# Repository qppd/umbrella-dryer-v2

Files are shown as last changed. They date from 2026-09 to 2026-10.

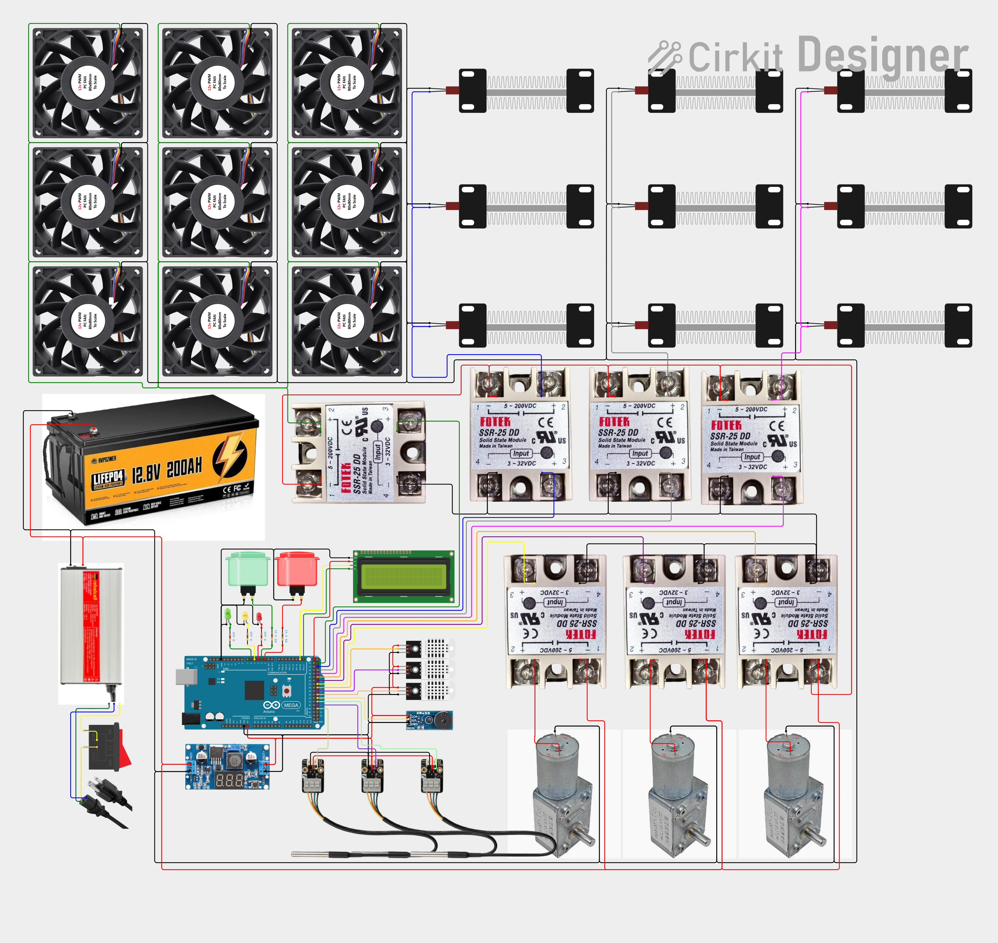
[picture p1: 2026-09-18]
wiring/circuit_image.png

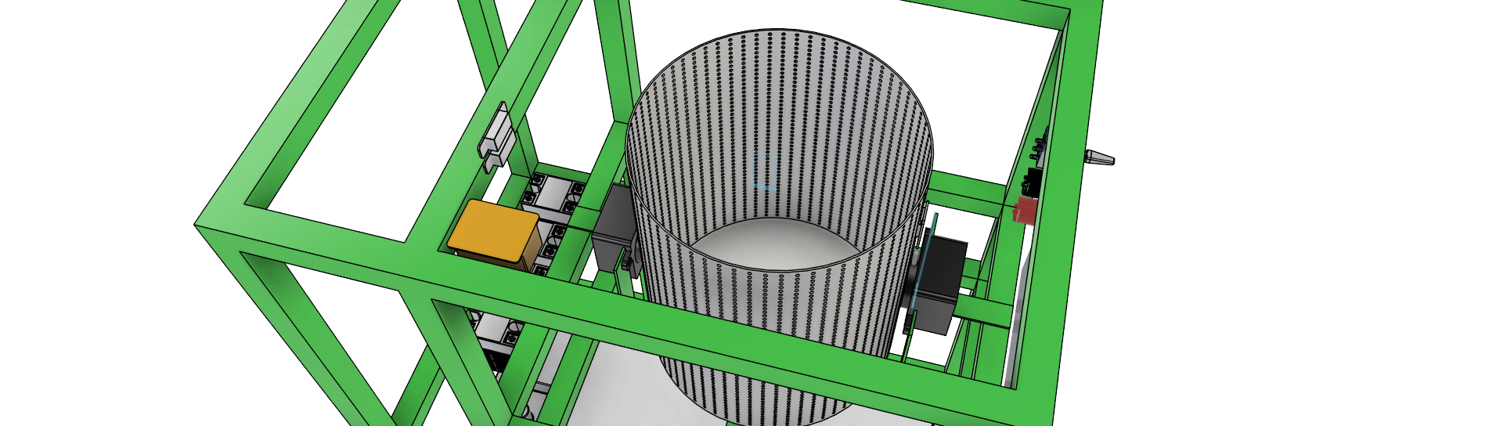
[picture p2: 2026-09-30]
model/UmbrellaDryerV2_8.png

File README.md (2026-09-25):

# Smart Umbrella Dryer

**Design and Development of a Multi-Umbrella Drying System with Energy Efficient Control**
Capstone project (BS Computer Engineering).

Dries **3 umbrellas simultaneously** (or any 1–3 mix) using heated forced air and sensor-based (humidity + temperature) feedback control — powered entirely by a **12V LiFePO4 battery** with energy-efficient staged duty cycling.

## How it works

1. Each umbrella mounts on its **own motorized station** — a SGM-370 worm gear motor (14 kg·cm) driving through a rigid coupling into a 6mm SS shaft (supported mid-span by a UCP06 pillow block), then a 6mm flange coupling to the umbrella hub — inside the drying chamber. Stations run independently; firmware stages one station at a time to stay within the BMS current budget.
2. **9× PTC ceramic heaters (12V 100W)** provide heating (3 per station), switched by **DC-output SSRs (SSR-40DD class)** driven directly from the Mega. **9× AVC 12V 4.5A blowers** circulate warm air (40–60°C) via direct PWM from the Mega.
3. **DHT22** (humidity) + **DS18B20** (heater-zone temp) drive the cycle on the **Arduino Mega 2560** — PREHEAT gates on temperature (45°C), and DRY auto-stops early once chamber humidity bottoms out at ≤ 60% RH (the "energy efficient control" of the study).
4. When chamber humidity drops below threshold → auto-shutoff + buzzer + green LED. Condensate drains passively (sloped floor → drain tube → drip tray).

## Core components

| Subsystem | Component |
|---|---|
| Controller | Arduino Mega 2560 |
| Heat | **9× PTC ceramic heaters 12V 100W** (3 per station), **LCTC DC-DC SSR 40A switched** |
| Rotation | **3× SGM-370 worm gear motors** 12V (14 kg·cm each), LCTC DC-DC SSR 10A switched |
| Fans | **9× AVC 12V 4.5A blowers** (3 per station), PWM via Mega D10/D11/D12 |
| Sensors | DHT22 (humidity) · DS18B20 (heater-zone temp) |
| Lid safety | **Magnetic Door Reed Switch Set NO/NC** (D22 — lid-closed sensor) · **Solenoid Lock 12VDC** (D23 via SSR-10A, fail-secure bolt lock) |
| Thermal safety | PTC self-regulation · firmware 65°C cutoff · BMS |
| UI | 16×2 LCD (I2C, pins 20/21), 3 status LEDs, buzzer, illuminated arcade start button |
| Mechanical | 3× drivetrains (rigid coupling 6×8mm → 6mm SS shaft on UCP06 pillow block → PETIYOUZA 6mm flange coupling), aluminum chassis |

## Where to start (read in this order)

| Order | Doc | Why |
|---|---|---|
| 1 | [docs/BOM.md](docs/BOM.md) | What to buy — printable shopping checklist |
| 2 | [docs/HARDWARE.md](docs/HARDWARE.md) | What each part is and its ratings |
| 3 | [model/README.md](model/README.md) | What you are building — dimensioned views |
| 4 | [docs/BLOCK-DIAGRAM.md](docs/BLOCK-DIAGRAM.md) | How everything wires together |
| 5 | [wiring/README.md](wiring/README.md) | Pin map and all connections (incl. lid interlock D22/D23) |
| 6 | [docs/SETUP.md](docs/SETUP.md) | Build it — numbered steps, check after each |
| 7 | [docs/FIRMWARE-GUIDE.md](docs/FIRMWARE-GUIDE.md) | Load and tune the code |
| 8 | [docs/TESTING.md](docs/TESTING.md) | Prove it works, record results |
| 9 | [docs/TROUBLESHOOTING.md](docs/TROUBLESHOOTING.md) | When a check fails |

Reference material: `docs/SYSTEM-ARCHITECTURE.md`, `docs/FLOWCHART.md`, `docs/STACKS.md`, `docs/SOURCING-ANNEX.md`.

## Verified performance

- **Cycle:** ≈ 15–25 min (light rain) – ~45 min (fully soaked), humidity auto-stop
- **Energy:** staged operation (1 station) ≈ 39.3A draw → ~3.7 h continuous, or ≈ 9.6 quick cycles (~29 umbrellas) per charge (144 Ah usable)
- **Margins:** motor torque ≥4.6× per station · BMS 5.5× vs staged DC draw · PTC self-regulation prevents thermal runaway
- **Cost:** ≈ ₱35,800 (battery + charger included; includes lid safety interlock: reed switch + solenoid lock + 4th SSR-10A)

## Key design decisions

1. **12V DC only** — no mains wiring, no RCD, no changeover switch. Safer, simpler, cheaper.
2. **DC-output SSRs for switching** — PTC draw (25A/station) and fan bus (40.5A) exceed PCB-relay ratings; SSR-40DD driven directly from Mega pins, SSR-10A for motors.
3. **PTC self-regulating** — heaters auto-limit current as temperature rises (secondary over-temperature protection).
4. **AVC blowers with PWM** — active air circulation for faster drying; PWM speed control via Mega `analogWrite()` (no ESC needed).
5. **Staged operation** — one station at a time keeps total current well within the 200A BMS limit.
6. **SGM-370 worm gear drivetrain** — self-locking, ≥4.6× torque margin, 6 RPM gentle speed; motor → rigid coupling → pillow-block-supported shaft → flange coupling.
7. **No-fuse 12V path** — main disconnect is a 50A DC rocker switch; over-current protection = 200A BMS + firmware cutoffs.

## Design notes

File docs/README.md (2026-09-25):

# Umbrella Dryer V2 — Documentation

> 3-station automated umbrella drying system. 12V DC battery power, no mains. PTC heaters + fan bus switched by DC-output SSRs, AVC blowers PWM-controlled directly from the Mega, worm gear motors for umbrella rotation. Arduino Mega 2560 controller.

---

## Quick start

| Doc | What it covers |
|---|---|
| [BOM.md](BOM.md) | Full bill of materials with prices, sellers, and URLs |
| [HARDWARE.md](HARDWARE.md) | Components, ratings, build standards, safety |
| [BLOCK-DIAGRAM.md](BLOCK-DIAGRAM.md) | Block diagrams of the electrical system |
| [SYSTEM-ARCHITECTURE.md](SYSTEM-ARCHITECTURE.md) | Architecture overview, power tree, safety design |
| [FIRMWARE-GUIDE.md](FIRMWARE-GUIDE.md) | Arduino sketch, pin map, wiring table |
| [SETUP.md](SETUP.md) | Step-by-step setup instructions |
| [TESTING.md](TESTING.md) | Test plan (L1 smoke test → L4 stress test) |
| [TROUBLESHOOTING.md](TROUBLESHOOTING.md) | Common issues and fixes |
| [SOURCING-ANNEX.md](SOURCING-ANNEX.md) | Where to buy everything (Lazada + makerlab.ph) |
| [../wiring/README.md](../wiring/README.md) | Pin map and all connections |
| [../model/README.md](../model/README.md) | 3D model views and dimensions |
| [references/](references/) | Original research paper and reference materials |

---

## System summary

- **Power:** 12V DC — 1× 200Ah LiFePO4 battery (no mains, no inverter)
- **Main disconnect:** 50A DC rocker switch (no fuses — 200A BMS + firmware cutoff; one station at a time ≈ 39A)
- **Heating:** 9× PTC ceramic heaters 12V 100W — 3 per station, SSR-40DD-switched
- **Fans:** 9× AVC 12V 4.5A blowers — 3 per station, direct PWM from Mega D10/D11/D12
- **Motors:** 3× SGM-370 worm gear 12V 6RPM 14 kg·cm, self-locking — rigid coupling → SS shaft on UCP06 pillow block → flange coupling to hub
- **Control:** Arduino Mega 2560, DHT22 + DS18B20, LCD 16×2 I2C (pins 20/21)
- **Thermal safety:** DS18B20 firmware cutoff 65°C + PTC self-regulation + BMS 200A (no thermal fuses)
- **Staged operation:** one station at a time (firmware-enforced 30s rotation)
- **Cost:** ≈ ₱35,800 (battery + charger included; PTC now ₱1,162 ea — original ₱484 listing out of stock; includes lid safety interlock: reed switch + solenoid lock + 4th SSR-10A)

---

## Build steps

1. **Order parts** — See SOURCING-ANNEX.md. Order battery first.
2. **Upload firmware** — See FIRMWARE-GUIDE.md. Install libraries, upload sketch.
3. **Calibrate buck** — Set LM2596S to 5.0V. Connect to Mega 5V pin (not barrel jack).
4. **Build frame** — 3-station frame for inverted umbrellas (700mm pitch).
5. **Mount drivetrain** — SGM-370 on aluminum plates; per station: rigid coupling 6×8mm → 6mm SS shaft through a UCP06 pillow block → 6mm flange coupling to umbrella hub.
6. **Wire power** — Battery → 50A DC rocker switch → 2-pin terminal → 150A bus bars → SSR branches (no fuses).
7. **Wire SSRs** — PTC + fan bus via SSR-40DD, motors via SSR-10A, all driven directly from Mega pins; blower PWM on D10/D11/D12.
8. **Wire sensors** — DHT22 (D2), DS18B20 (D3), LCD I2C (D20/D21).
9. **Test** — Follow TESTING.md: L1 smoke test → L2 component → L3 integration → L4 stress.
10. **Deploy** — Place umbrellas, press button, dry.

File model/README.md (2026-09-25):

# Umbrella Dryer V2 — 3D Model

> This folder contains the 3D model of the umbrella dryer frame and station layout.

---

## Model overview

The 3D model shows:
- **3-station frame** — holds 3 umbrellas inverted for drying
- **Motor mounts** — SGM-370 worm gear motors on aluminum plates
- **Drivetrain** — per station: SGM-370 motor → rigid coupling 6×8mm → 6mm × 300mm shaft → UCP06 pillow block (shaft passes through the bearing's middle) → PETIYOUZA 6mm flange coupling → umbrella hub; all bolted to the aluminum plate
- **PTC heater placement** — 3× PTC ceramic heaters per station, positioned for airflow
- **AVC blower placement** — 3× 80mm blowers per station, positioned for air circulation
- **Electronics enclosure** — Mega, SSR modules, buck converter, reed switch, solenoid lock
- **Battery compartment** — 1× LiFePO4 200Ah battery
- **Drip tray** — under each station for water collection

---

## File formats

| File | Use |
|---|---|
| `.step` / `.stp` | CAD interchange (Fusion 360, SolidWorks, FreeCAD) |
| `.stl` | 3D printing |
| `.f3d` | Fusion 360 native |

---

## Key dimensions

| Part | Dimension |
|---|---|
| Station spacing | **700mm** center-to-center |
| Umbrella hub height | ~300mm from base |
| Motor mount plate | 100×80mm aluminum 6mm |
| Motor drivetrain | rigid coupling 6×8mm · 6mm × 300mm SS shaft · UCP06 pillow block (mid-shaft) · PETIYOUZA flange, 6mm bore (motor → shaft → hub) |
| PTC heater spacing | ≥ 30mm between elements (airflow gap) |
| Fan duct clearance | ≥ 10mm from umbrella fabric |
| Chamber internal W × D × H | 2200 × 800 × 1300mm |

---

## Assembly notes

1. Print or fabricate motor mount plates from aluminum.
2. Mount each SGM-370 motor directly onto its plate; align motor output shaft with umbrella hub.
3. Drivetrain per station, in order: rigid coupling 6×8mm on the motor output shaft, then the 6mm × 300mm shaft through the UCP06 pillow block (shaft centered in the bearing), then the PETIYOUZA 6mm flange coupling to the umbrella hub. Motor and pillow block share the aluminum plate.
4. Verify: spin by hand. Should rotate freely with no binding. Motor is self-locking.
5. Position AVC blowers to blow air across PTC heaters toward umbrella fabric.
6. Wire everything per [wiring/README.md](../wiring/README.md) and [HARDWARE.md](../HARDWARE.md).

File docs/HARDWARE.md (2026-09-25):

# Hardware Reference — 12V DC System

> **Major revision:** This version replaces the 220V mains + inverter architecture with an
> all-12V DC system. No mains voltage, no inverter, no RCD, no changeover switch, no SSR-40DA.
> All heating, fans, and motors run directly off the 12V LiFePO4 battery.
>
> SSR-40DD DC-output solid-state relays for PTC heaters and fan bus (no automotive relays,
> no NPN driver stage); thermal fuses removed — over-temp relies on PTC self-regulation +
> DS18B20 firmware cutoff; pin map reconciled across all docs; LCD I2C corrected to Mega
> pins 20/21 (not A4/A5); staged operation mandatory (≤1 station at a time).

---

## 1. System block diagram

```mermaid
graph TB
    subgraph Power["12V DC Power System"]
        BAT["1× LiFePO4 200Ah<br/>(12.8V nominal)<br/>BMS 200A"]
    end

    subgraph Control["Control Layer"]
        MEGA["Arduino Mega 2560<br/>5V from buck"]
        DHT["DHT22<br/>(mid-chamber)"]
        DS["DS18B20<br/>(heater airstream)"]
        LCD["LCD 16×2 I2C (20/21)"]
        BTN["Button D14"]
        BUZ["Buzzer D18"]
        LED["Status LEDs D15–D17"]
        REED["Lid Reed Switch<br/>D22 (closed = LOW)"]
        SOL["Solenoid Lock SSR-10A<br/>D23 (HIGH = UNLOCK pulse)"]
    end

    subgraph SSR_BLOCK["SSR driver stages ×4 (D4/D6/D8/D13)"]
        SSR["SSR-40DD<br/>Input 3–32VDC<br/>DC output, 40A"]
    end

    subgraph Station1["Station 1"]
        SSR_H1["SSR-40DD<br/>(D4 direct)"]
        PTC1A["PTC Heater 1"]
        PTC1B["PTC Heater 2"]
        PTC1C["PTC Heater 3"]
        SSR_M1["SSR-10A<br/>(D5 HIGH=ON)"]
        MTR1["SGM-370 Motor<br/>+ drivetrain"]
        FAN1A["AVC Blower 1"]
        FAN1B["AVC Blower 2"]
        FAN1C["AVC Blower 3"]
    end

    subgraph Station2["Station 2"]
        SSR_H2["SSR-40DD<br/>(D6 direct)"]
        PTC2A["PTC Heater 4"]
        PTC2B["PTC Heater 5"]
        PTC2C["PTC Heater 6"]
        SSR_M2["SSR-10A<br/>(D7 HIGH=ON)"]
        MTR2["SGM-370 Motor"]
        FAN2A["AVC Blower 4"]
        FAN2B["AVC Blower 5"]
        FAN2C["AVC Blower 6"]
    end

    subgraph Station3["Station 3"]
        SSR_H3["SSR-40DD<br/>(D8 direct)"]
        PTC3A["PTC Heater 7"]
        PTC3B["PTC Heater 8"]
        PTC3C["PTC Heater 9"]
        SSR_M3["SSR-10A<br/>(D9 HIGH=ON)"]
        MTR3["SGM-370 Motor"]
        FAN3A["AVC Blower 7"]
        FAN3B["AVC Blower 8"]
        FAN3C["AVC Blower 9"]
    end

    subgraph FanBus["AVC BLOWER POWER BUS"]
        FAN_SSR["SSR-40DD<br/>(D13 direct)"]
    end

    subgraph BuckStage["Buck converter"]
        BUCK["LM2596S 12V→5V<br/>(feeds Mega 5V pin only)"]
    end

    BAT --> BUS["12V Bus"]
    BUS --> SSR_H1 & SSR_H2 & SSR_H3 & FAN_SSR
    BUS --> SSR_M1 & SSR_M2 & SSR_M3
    BUS --> BUCK --> MEGA
    MEGA --> DHT & DS & LCD & BTN & BUZ & LED & REED & SOL

    SSR_BLOCK --> SSR_H1 & SSR_H2 & SSR_H3 & FAN_SSR

    SSR_H1 --> PTC1A & PTC1B & PTC1C
    SSR_H2 --> PTC2A & PTC2B & PTC2C
    SSR_H3 --> PTC3A & PTC3B & PTC3C

    SSR_M1 --> MTR1
    SSR_M2 --> MTR2
    SSR_M3 --> MTR3

    FAN_SSR --> FAN1A & FAN1B & FAN1C
    MEGA -. "D10/D11/D12 PWM" .-> FAN1A & FAN2A & FAN3A
```

---

## 2. Module spec sheets

### Controller — Arduino Mega 2560 R3

| Spec | Value | Design implication |
|---|---|---|
| MCU | ATmega2560, AVR 8-bit @ 16 MHz | Bare-metal firmware, no OS |
| Digital I/O | 54 (15 PWM) | 20 used (D2–D18 + D22/D23) — headroom remains |
| Flash / SRAM / EEPROM | 256 KB / 8 KB / 4 KB | Use `F()` macro for string literals |
| Logic level | 5V | SSR inputs, PWM fan control compatible |
| Power input | **5V pin from buck** | Never 12V on the barrel jack |
| Serial | USB + Serial0 (pins 0/1), 115200 debug | Keep 0/1 free during development |
| I2C | Hardware pins **20 (SDA) / 21 (SCL)** | NOT A4/A5 — those are ADC on the Mega |

### AVC DC blower fans — 9× 80mm (3 per station)

| Spec | Value | Note |
|---|---|---|
| Type | AVC Super High Speed Blower DC, 12V, 4.5A | 80×80×38mm, 5 blades, ball bearing, PWM control |
| Rated voltage | 12V DC | Direct from the 12V fan power bus |
| Current draw | 4.5A each @ full speed | 3 per station = 13.5A per station |
| PWM control | `analogWrite()` 0–255 from Mega | 5V logic compatible; no ESC needed |
| Control pins | D10 (station 1), D11 (station 2), D12 (station 3) | 3 leads per pin (parallel signal wires) |
| Role | Forced convection — pushes heated air across the wet canopy | 3 blowers per station for even airflow coverage |

> **PWM control:** Use `analogWrite(pin, value)` where `value` is 0–255. No Servo library needed. The fan bus SSR (D13) must be ON for the blowers to receive power. Full speed = `analogWrite(D, 255)`.

### PTC ceramic heaters — 9× 12V 100W (3 per station)

| Spec | Value | Note |
|---|---|---|
| Rated | 12V, 100W each (~8.3A) | Self-regulating — resistance rises with temperature |
| Self-regulation | PTC effect: power drops as surface temp rises | No thermostat needed for basic overheat protection |
| Mounting | Station bracket, aimed at canopy underside | ≥ 5 cm clearance to wiring, sensors, and plastic parts |
| Role | Provides 40–60 °C warm airflow for drying | 3 heaters per station = 300W per station |
| Protection | PTC self-limiting + DS18B20 firmware 65 °C cutoff | No thermal fuse — BMS + firmware are the only protections |

### Motors — 3× SGM-370 worm gear (one per station)

| Parameter | Value |
|---|---|
| Rated | 12 V, 6 RPM, **14 kg·cm**, ~0.2 A @ rated load |
| Stall | 28 kg·cm, ~0.8 A |
| Shaft | 6 mm Ø output shaft, single shaft | Drivetrain per station: 6×8mm rigid coupling → 6mm × 300mm SS shaft (passes through a UCP06 pillow block mid-shaft) → 6mm-bore PETIYOUZA flange coupling → umbrella hub; motor + pillow block bolted to the 6mm aluminum plate |
| Behavior | **Self-locking** (worm not back-drivable); stall-tolerant |

### Battery bank + power distribution

| Spec | Value | Note |
|---|---|---|
| Battery | 1× LiFePO4 12.8V 200Ah battery | 200Ah total, 2,560 Wh |
| BMS | Built-in (200A) | Over-charge, over-discharge, over-current, short-circuit |
| Wire gauge | 8 AWG battery→bus · 10 AWG heater/fan branches · 18 AWG motor · 20 AWG logic | All stranded copper |
| Connectors | Screw terminals (battery → 2-pin terminal → bus bars) | No XT60 — 8 AWG exceeds typical XT60 sizing in this layout |

### SSR architecture

| SSR | Type | Rating | Driven by | Switches | Current |
| Station 1 PTC | LCTC DC-DC SSR 40A (DC output) | 40A, input 3–32VDC | D4 direct | 3× PTC heaters | ~25A |
| Station 2 PTC | LCTC DC-DC SSR 40A (DC output) | 40A, input 3–32VDC | D6 direct | 3× PTC heaters | ~25A |
| Station 3 PTC | LCTC DC-DC SSR 40A (DC output) | 40A, input 3–32VDC | D8 direct | 3× PTC heaters | ~25A |
| Fan bus | LCTC DC-DC SSR 40A (DC output) | 40A, input 3–32VDC | D13 direct | 9× AVC blowers | ~40.5A |
| Motor 1 | LCTC DC-DC SSR 10A (DC output) | 10A @ 30VDC | D5 HIGH = ON | SGM-370 #1 | ~0.8A |
| Motor 2 | LCTC DC-DC SSR 10A (DC output) | 10A @ 30VDC | D7 HIGH = ON | SGM-370 #2 | ~0.8A |
| Motor 3 | LCTC DC-DC SSR 10A (DC output) | 10A @ 30VDC | D9 HIGH = ON | SGM-370 #3 | ~0.8A |
| Lid lock | LCTC DC-DC SSR 10A (DC output) | 10A @ 30VDC | D23 HIGH = UNLOCK | Solenoid lock | ~0.65A (pulsed) |
**Why LCTC DC-DC SSR for PTC:** 3× 100W PTC = 25A — over the 10A rating of PCB optocoupler modules. LCTC DC-DC SSR 40A handles DC output at 40A with no mechanical contacts. Driven directly from Mega digital pins (3–32VDC input); no NPN transistors, no base resistors, no flyback diodes required. Heatsink required (≈1 W/A → ~25 W at 25A). Motor SSRs (10A): minimal dissipation at 0.8A.

### Lid solenoid lock — 1× Makerlab Solenoid Lock 12VDC

Fail-secure lid bolt lock for the chamber front cover. **Normally-LOCKED** (spring holds the bolt out) with **0 A draw**. Energizing pulls the bolt in (UNLOCK).

| Spec | Value | Note |
|---|---|---|
| Type | 12 VDC solenoid lock (bolt) | Normally-locked / fail-secure |
| Operating voltage | 12 V DC | Switched by the 4th LCTC DC-DC SSR-10A (D23) |
| Current | ~650 mA @ 12 V (500 mA @ 9 V) | **When energized only** — pulsed ~3 s to unlock |
| Duty | Design for 1–10 s activation | **Do not hold energized** — pulse-only |
| Wire length | ~222 mm | On-board, mounts to the lid/frame |
| Role | Locks the lid shut during a drying cycle; unlocks at COMPLETE | Safety: prevents access to spinning/heated chamber |

### Lid reed switch — 1× Magnetic Door Reed Switch Set NO/NC (Makerlab)

Magnetic door/window switch used as the lid-closed detector.

| Spec | Value | Note |
|---|---|---|
| Type | Magnetic reed switch set (NO / NC configurable) | Includes magnet + reed housing |
| Contacts | Use **NO** (normally open) | Closed when the magnet is near (lid shut) |
| Wiring | D22 (INPUT_PULLUP) + GND | Lid closed = D22 LOW; lid open = HIGH |
| Role | Start-interlock: the machine will not start while the lid is open | Safety |

---

## 3. Pin map

| Arduino Pin | Function | Direction | Active level | Notes |
|---|---|---|---|---|
| D0 / D1 | Serial TX/RX | Debug | — | Keep free during development |
| **D2** | **DHT22 data** | Input | — | 10 kΩ pull-up to 5V |
| **D3** | **DS18B20 data** | Input | — | 4.7 kΩ pull-up to 5V (1-Wire) |
| **D4** | **PTC SSR — Station 1** | Output | HIGH = ON | SSR-40DD direct drive |
| **D5** | **Motor SSR — Station 1** | Output | HIGH = ON | SSR-10DD direct drive |
| **D6** | **PTC SSR — Station 2** | Output | HIGH = ON | SSR-40DD direct drive |
| **D7** | **Motor SSR — Station 2** | Output | HIGH = ON | SSR-10DD direct drive |
| **D8** | **PTC SSR — Station 3** | Output | HIGH = ON | SSR-40DD direct drive |
| **D9** | **Motor SSR — Station 3** | Output | HIGH = ON | SSR-10DD direct drive |
| **D10** | **PWM Fan — Station 1** | Output (PWM) | — | `analogWrite(D10, val)` 0–255 |
| **D11** | **PWM Fan — Station 2** | Output (PWM) | — | `analogWrite(D11, val)` 0–255 |
| **D12** | **PWM Fan — Station 3** | Output (PWM) | — | `analogWrite(D12, val)` 0–255 |
| **D13** | **Fan bus SSR** | Output | HIGH = ON | SSR-40DD direct drive |
| **D14** | **Start button** | Input | LOW = pressed | INPUT_PULLUP |
| **D15** | **Red LED** | Output | HIGH = ON | 220 Ω series |
| **D16** | **Yellow LED** | Output | HIGH = ON | 220 Ω series |
| **D17** | **Green LED** | Output | HIGH = ON | 220 Ω series |
| **D18** | **Buzzer** | Output | HIGH = ON | Active buzzer |
| **D22** | **Lid reed switch** | Input | LOW = LID CLOSED | INPUT_PULLUP, NO reed → GND |
| **D23** | **Lid solenoid lock SSR** | Output | HIGH = UNLOCK (pulse ~3 s) | SSR-10A direct drive |
| **20 (SDA)** | **LCD I2C SDA** | I2C | — | addr 0x27 or 0x3F |
| **21 (SCL)** | **LCD I2C SCL** | I2C | — | Mega hardware I2C |

> SSR pins (D4/D6/D8/D13) are active-HIGH: no input current at boot keeps them OFF.
> Motor SSR pins (D5/D7/D9) are also active-HIGH with SSR-10DD, floating pin = OFF at boot.
> The `allOff()` function in `setup()` enforces a safe state regardless.

---

## 4. Power budget

| Load | Per unit | Qty | Total | Protection |
|---|---|---|---|---|
| PTC heater (12V 100W) | 8.3A | 9 | 74.7A (all on) | SSR-40DD per station |
| AVC blower (12V 4.5A) | 4.5A | 9 | 40.5A (all on) | SSR-40DD fan bus |
| SGM-370 motor | 0.2A / 0.8A stall | 3 | 0.6A / 2.4A | SSR-10DD |
| Arduino Mega + sensors | 0.1A | 1 | 0.1A | Buck converter |
| Lid solenoid lock | 0.65A when pulsed (~3 s) | 1 | **~0 A avg** (0 A while locked) | SSR-10A |
| **Worst-case total** | | | **~104A** | **BMS 200A** |

> **Staged operation is mandatory.** One station full load = ~39.3A (3 PTC + 3 blowers + motor + logic).
> The firmware rotates stations every 30 s so only one is active at a time. Two stations
> simultaneously = ~78.6A — within the BMS 200A rating but staged operation preserves battery
> current budget and follows the study's energy-efficient control strategy. Firmware enforces this limit.

**Runtime estimates (1× 200 Ah battery, 144 Ah usable @ 80% DoD × 90% EoL):**

| Mode | Draw | Estimated runtime |
|---|---|---|
| Single station (staged, 1 at a time) | ~39.3A | ~3.7 hours |
| Quick drying cycle (3 umbrellas) | 27 min | ≈ 9.6 cycles per charge |
| Standard drying cycle (fully soaked) | 57 min | ≈ 4.4 cycles per charge |
| Standby (sensors + idle) | ~0.5A | ≈ 12 days |

> See `docs/BOM.md` §7d for the full capacity-requirement analysis.

---

## 5. Station layout

| Parameter | Decision |
|---|---|
| Canopy state when drying | **Half-open** — projected Ø ≈ 650 mm |
| Chamber internal W × D × H | **2200 × 800 × 1300 mm** |
| Station layout | Single row of 3 stations on the long axis, pitch **700 mm** |
| Clearance | 75 mm each side; 50 mm between adjacent canopies (passes ≥50 mm rule) |
| Services | 9× PTC heaters + 9× AVC blowers + 12V power bus + DHT22 + DS18B20 |

---

## 6. Electrical build standards

| Item | Standard |
|---|---|
| Wire gauge | 8 AWG battery main · 10 AWG heater/fan branches · 18 AWG motor · 20 AWG logic · 22 AWG signals |
| Grounding | Single-point: all returns → battery − rail; chassis bonded at one bolt |
| Connectors | Screw terminals (battery → 2-pin terminal → bus bars) · JST-XH for sensor harnesses |
| Pass-throughs | Rubber grommets at every chamber wall penetration |

---

## 7. Safety provisions

| Hazard | Mitigation |
|---|---|
| **Short circuit** | BMS over-current (200A) + PTC self-regulation |
| **Over-temperature (heaters)** | PTC self-regulating + DS18B20 firmware 65 °C cutoff |
| **Over-temperature (chamber)** | DHT22 reads ambient; firmware shuts all loads if T > 65 °C |
| **Battery over-discharge** | BMS low-voltage cutoff (~10V pack) |
| **Battery over-charge** | BMS high-voltage cutoff (~14.6V pack) |
| **Accidental heater on at boot** | SSR has no input current at boot = OFF; `allOff()` called first in `setup()` |
| **Water ingress** | Waterproof sensors; grommets; silicone-sealed seams; no bare connections below 5 cm |
| **Lid open / access during operation** | **Lid safety interlock:** reed switch (D22) blocks start while the lid is open; solenoid lock (D23, fail-secure) holds the lid shut for the whole cycle — no access to rotating or heated elements while running |
| **RCD / GFCI** | **Not required** — SELV system, ≤ 50V DC |

> **No hardware fuse backstop.** This build intentionally omits all blade fuses, ANL fuses,
> and thermal fuses. Over-current protection is provided solely by the BMS (200A) and PTC
> self-regulation. Over-temperature protection is provided solely by PTC self-regulation and
> the DS18B20 firmware cutoff. The staged-operation firmware prevents sustained high-current
> draw by limiting the system to one station at a time (~39A vs 200A BMS capacity).

### What was removed from previous revisions

| Removed component | Reason |
|---|---|
| 220V mains + changeover switch | No mains voltage in the system |
| RCD/GFCI | Not needed — 12V DC SELV cannot cause electric shock |
| SSR-40DA solid-state relays | Replaced by SSR-40DD DC-output SSRs for PTC + SSR-10DD for motors |
| 3000W pure sine inverter | All loads run natively on 12V DC |
| 14.6V lead-acid charger | LiFePO4 charger only |
| Mains rocker switches | Not needed — 50A DC rocker switch for main power |
| 40A automotive relays (×4) | Replaced by SSR-40DD — no mechanical contacts, no NPN driver needed |
| NPN driver stage (2N2222 ×4) | SSR-40DD driven directly from Mega pins |
| 1kΩ base resistors ×4 | No longer needed — no NPN transistors |
| 10kΩ pull-down resistors ×4 | No longer needed — SSR has no input current at boot |
| 1N4007 flyback diodes ×4 | No longer needed — no relay coils |
| 50A ANL main fuse | BMS 200A is the sole over-current protection |
| 50A disconnect switch | Replaced by 50A DC rocker switch (main power disconnect) |
| 30A blade fuses ×3 (PTC branches) | Removed — SSR handles switching; BMS is backstop |
| 30A blade fuse (fan bus) | Removed — SSR handles switching; BMS is backstop |
| 3A blade fuses ×3 (motors) | Removed — BMS is backstop |
| 3A blade fuse (logic) | Removed — BMS is backstop |
| 130 °C thermal fuses ×9 | Removed — PTC self-regulation + DS18B20 firmware cutoff replaces them |

---

## 8. Revision history

| Rev | Hardware change |
|---|---|
| Rev 2 | SSR-25DD + BTS7960 + single carousel motor + (optional) MLX90614 |
| Rev 3 | Relays replace SSR + driver; MLX90614 dropped |
| Rev 4 | 3 independent stations (3× motors + flange couplings); 25A main fuse |
| Rev 5 | Mains heat: 2× 1500W PTC heater-fans via 2× SSR-40DA; RCD added |
| Rev 6 | Dual source: wall outlet OR 3000W inverter via changeover; 2× 200Ah LiFePO4 |
| Rev 7 | Complete 12V DC redesign: 9× PTC + 9× AVC blower + 3× SGM-370; no mains, no inverter |
| Rev 8 | Fuse plan fixed (50A main, 30A PTC/fan, per-heater 130°C thermal fuse); PTC relays upgraded to 40A automotive; pin map reconciled; LCD I2C corrected to pins 20/21; staged operation mandatory |
| **Rev 9** | **No-fuse SSR build: all fuses, NPN driver stages, and thermal fuses removed; 40A automotive relays replaced by SSR-40DD DC-output SSRs driven directly from Mega pins; protection = BMS 200A + PTC self-regulation + DS18B20 firmware cutoff; added 50A DC rocker switch for main power disconnect** |
| **Rev 10** | **Lid safety interlock: added a Magnetic Door Reed Switch Set (D22) so the machine will not start while the chamber lid is open, and a Makerlab Solenoid Lock 12VDC switched by a 4th LCTC DC-DC SSR-10A (D23, fail-secure) so the lid is locked for the whole cycle and only pulsed open at COMPLETE / on a 2 s hold to load** |

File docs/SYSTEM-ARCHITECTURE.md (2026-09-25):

# System Architecture — 12V DC Umbrella Dryer

Pure 12V DC umbrella dryer. No mains, no inverter, no AC anywhere. Everything runs from a single LiFePO4 battery through direct DC distribution. AVC blowers are PWM-controlled directly from the Mega (no ESCs). SSR-40DD switches PTC heaters and fan bus; SSR-10A switches worm motors.

## 1. Layered architecture

```mermaid
flowchart TD
    subgraph L5["LAYER 5 — Human interface"]
        LCD["16x2 LCD (I2C, pins 20/21)"]
        BTN["Start button (D14)"]
        LED["3× status LEDs (D15–D17)"]
        BUZ["Buzzer (D18)"]
    end

    subgraph L4["LAYER 4 — Control"]
        FW["Arduino Mega 2560<br/>IDLE / PREHEAT / DRY / COOL / DONE / CUTOFF<br/>Staged operation: 1 station at a time"]
    end

    subgraph L3["LAYER 3 — Sensing"]
        DHT["DHT22 — chamber humidity + ambient temp"]
        DS["DS18B20 — heater-zone temp (safety signal)"]
        REED["Reed switch (D22) — lid closed (start-interlock signal)"]
    end

    subgraph L2["LAYER 2 — Actuation"]
        subgraph PTC_SSR["PTC heater SSRs ×3 (SSR-40DD, active-HIGH)"]
            PR1["D4 → station 1 PTC"]
            PR2["D6 → station 2 PTC"]
            PR3["D8 → station 3 PTC"]
        end
        subgraph MOT_SSR["Motor SSRs ×3 (SSR-10A, active-HIGH)"]
            MR1["D5 → station 1 motor"]
            MR2["D7 → station 2 motor"]
            MR3["D9 → station 3 motor"]
        end
        FAN_SSR["Fan bus SSR (D13 → SSR-40DD, active-HIGH)"]
        PWM_FAN["PWM blower control ×3 (D10–D12) — analogWrite"]
        SOL["Lid solenoid lock SSR-10A (D23) — fail-secure, pulse-unlock"]
    end

    subgraph L1["LAYER 1 — Power"]
        BANK["1× LiFePO4 12.8V 200Ah<br/>BMS 200A"]
        BUS["12V DC distribution bus<br/>(2× 10-terminal copper bus bars)"]
        BUCK["LM2596S buck 12V → 5V"]
    end

    subgraph L0["LAYER 0 — Plant (mechanical + thermal)"]
        CH["3 drying stations"]
        PTC_ALL["PTC heaters 100W ×9<br/>(PTC self-regulation)"]
        BLOW_ALL["AVC blowers ×9 (3 per station)"]
        MOT_ALL["SGM-370 worm motors ×3"]
    end

    L0 --> L3
    L3 --> L4
    L4 --> L2
    L2 --> L0
    L1 --> L2
    L1 --> L4
    L4 <--> L5
```

## 2. Power architecture

Single domain: 12V DC throughout. Staged operation keeps one station active at a time (~39.3A). BMS 200A provides over-current protection.

```mermaid
flowchart LR
    BANK["LiFePO4 Battery<br/>1× 200Ah<br/>2560 Wh"]
    BMS["BMS 200A<br/>per pack"]
    BUS["12V DC bus<br/>(2× 10-terminal copper bar)"]

    BANK --> BMS --> BUS

    BUS -->|Station 1 PTC (~25A)| S1["Station 1<br/>PTC + Motor + Blower"]
    BUS -->|Station 2 PTC (~25A)| S2["Station 2<br/>PTC + Motor + Blower"]
    BUS -->|Station 3 PTC (~25A)| S3["Station 3<br/>PTC + Motor + Blower"]
    BUS -->|Fan bus (~40.5A)| FANS["Fan bus<br/>9× AVC blowers"]
    BUS -->|Logic (~0.1A)| LOGIC["5V buck<br/>Mega + sensors"]
```

### Per-station load budget

| Component | Qty | Voltage | Each | Total (station) |
|---|---|---|---|---|
| PTC heater | 3 | 12V | 100W / 8.3A | 300W / 25A |
| AVC blower | 3 | 12V | ~54W / 4.5A | ~162W / 13.5A |
| SGM-370 motor | 1 | 12V | ~2.4W / 0.2A | ~2.4W / 0.8A stall |
| **Station total (peak)** | — | — | — | **~464W / ~39.3A** |

### System-wide fuse table

No fuses in the circuit. BMS 200A is the sole over-current protection.

| Branch | Load | Protection |
|---|---|---|
| Main | 12V DC bus (one station at a time) | BMS 200A |
| Station 1 PTC | ~25A | BMS 200A + PTC self-regulation |
| Station 2 PTC | ~25A | BMS 200A + PTC self-regulation |
| Station 3 PTC | ~25A | BMS 200A + PTC self-regulation |
| Motor 1/2/3 | ~0.8A each | BMS 200A |
| Fan bus | ~40.5A | BMS 200A |
| Logic | ~0.1A | BMS 200A + LM2596S |

## 3. Control — pin mapping

| Arduino Pin | Function | Actuator | Drive | Active |
|---|---|---|---|---|
| D2 | DHT22 data | Chamber humidity sensor | 10kΩ pull-up | — |
| D3 | DS18B20 data | Temperature probe | 4.7kΩ pull-up | — |
| D4 | Station 1 PTC | 3× PTC (SSR-40DD) | Direct drive | HIGH |
| D5 | Station 1 motor | SGM-370 (SSR-10A) | Direct drive | HIGH |
| D6 | Station 2 PTC | 3× PTC (SSR-40DD) | Direct drive | HIGH |
| D7 | Station 2 motor | SGM-370 (SSR-10A) | Direct drive | HIGH |
| D8 | Station 3 PTC | 3× PTC (SSR-40DD) | Direct drive | HIGH |
| D9 | Station 3 motor | SGM-370 (SSR-10A) | Direct drive | HIGH |
| D10 | Station 1 blower | AVC blower PWM | `analogWrite` 0–255 | — |
| D11 | Station 2 blower | AVC blower PWM | `analogWrite` 0–255 | — |
| D12 | Station 3 blower | AVC blower PWM | `analogWrite` 0–255 | — |
| D13 | Fan bus enable | SSR-40DD → 9 blowers | Direct drive | HIGH |
| D14 | Start button | Push-button | INPUT_PULLUP | LOW |
| D15 | Red LED | Heating active | 220Ω | HIGH |
| D16 | Yellow LED | Cycle running / cooling | 220Ω | HIGH |
| D17 | Green LED | Ready / done | 220Ω | HIGH |
| D18 | Buzzer | Active buzzer | — | HIGH |
| D22 | Lid reed switch | Lid-closed sensor (NO reed) | INPUT_PULLUP | LOW (CLOSED) |
| D23 | Lid solenoid lock | SSR-10A → solenoid lock | Direct drive | HIGH (UNLOCK pulse) |
| 20 (SDA) | LCD I2C | 16×2 LCD | I2C | — |
| 21 (SCL) | LCD I2C | 16×2 LCD | I2C | — |

> **All SSRs are active-HIGH.** Floating pins at boot = SSR OFF. `allOff()` in `setup()` enforces safe state.
> **PWM fans** use `analogWrite()` — no Servo library needed. 5V logic compatible with AVC blowers.

## 4. Safety layers

```mermaid
flowchart TD
    A["DS18B20 reads heater-zone temp"] --> B{"Temp > 65 C ?"}
    B -- Yes --> C["Firmware cuts ALL loads<br/>Latched until T < 50 C"]
    B -- No --> D["Normal operation"]

    C --> E{"Temp still rising ?"}
    E -- Yes --> F["PTC self-regulation<br/>Resistance rises with temp"]
    E -- No --> G["Normal operation continues"]

    F --> H["Heater auto-limits current"]

    I["BMS cell protection"] --> J{"Low V / over-current / over-temp ?"}
    J -- Yes --> K["Battery protected<br/>BMS disconnects"]
    J -- No --> O["Bank supplies bus"]
```

### Defense-in-depth thermal protection

| Layer | Mechanism | Trip point | Response time | Resettable? |
|---|---|---|---|---|
| **Firmware interlock** | DS18B20 + software cutoff | > 65 °C | < 1 s | Yes (auto when T < 50 °C) |
| **PTC self-regulation** | Resistance rises with temperature | ~150–200 °C | Passive / instant | Yes |
| **BMS protection** | Cell-level hardware cutoff | Per-pack thresholds | Hardware | Auto (some conditions) |

> **Three independent thermal/electrical layers** protect against heater runaway. No thermal fuses.

## 5. One drying cycle — sequence

```mermaid
sequenceDiagram
    participant U as User
    participant FW as Mega 2560
    participant S as Sensors (DHT22 + DS18B20)
    participant R as SSRs (D4–D13)
    participant P as PWM Fans (D10–D12)

    U->>FW: Press start (D14)
    FW->>S: Self-test read (humidity, temp)
    FW->>R: Fan bus ON (D13)
    FW->>P: Blowers FULL (analogWrite(D, 255))

    Note over FW,R,P: PREHEAT — staged: one station PTC at a time (30s each)

    loop Every 500 ms
        FW->>S: Read humidity H, zone temp T
        alt T > 65 °C (thermal alarm)
            FW->>R: ALL OFF — latched
            Note over FW: CUTOFF — retry only when T < 50 °C
        else H above threshold (wet)
            FW->>R: PTC ON for active station (rotates every 30s)
            FW->>P: Blower PWM FULL for active station
        else H below threshold for 5 min
            FW->>R: ALL OFF
            Note over FW: COMPLETE
        end
    end

    Note over FW: DRY phase — staged motor + PTC + blowers, max 15 min (auto-stop at ≤ 60% RH)
    Note over FW: COOL phase — blowers only, 2 min, then ALL OFF

    FW-->>U: COMPLETE on LCD + buzzer 3×
    U->>U: Unload umbrellas, empty drip tray
```

## 6. Design principles

| Principle | Realization |
|---|---|
| **No mains anywhere** | Entire system 12V DC — no RCD, no changeover, no AC wiring |
| **Defense in depth on heat** | DS18B20 → PTC self-regulation → BMS: three layers |
| **Staged operation** | Firmware rotates stations every 30s; only one station's heaters active at a time; keeps draw ~39.3A |
| **Direct-drive SSRs** | All SSRs active-HIGH, driven directly from Mega pins — no NPN transistors, no optocoupler modules |
| **PWM blower control** | AVC blowers accept 5V PWM directly from Mega — no ESC needed |
| **Worm drive self-locking** | SGM-370 motors hold position when de-energized — no brake, no holding current |
| **Lid safety interlock** | Reed switch (D22) refuses start while the lid is open; fail-secure solenoid lock (D23) holds the lid shut for the whole cycle — no access to rotating/heated elements while running |
| **No fuses** | BMS 200A is the sole over-current protection; no blade fuses, ANL fuses, or thermal fuses |

## 7. Deliberate non-features

- **No mains connection** — Eliminates RCD, changeover switch, AC wiring
- **No per-station humidity sensor** — Single DHT22 is the shared control variable
- **No motor speed control** — 6 RPM fixed
- **No current sensing** — Jam detection via observation
- **No PID temperature control** — PTC self-regulation + firmware on/off hysteresis
- **No ESCs** — AVC blowers use direct PWM, no brushless motor controllers needed
- **No thermal fuses** — Relies on PTC self-regulation + firmware cutoff + BMS
- **No fuses** — BMS 200A is the sole over-current protection

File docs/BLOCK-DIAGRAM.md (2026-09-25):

# Electrical Block Diagram — 12V DC Umbrella Dryer

> **Pure 12V DC system.** No mains voltage. No inverter. No RCD/GFCI.
> All heating, motor, and fan loads run from a 12V LiFePO4 battery
> through direct DC distribution. Arduino Mega 2560 provides closed-loop
> control with LCTC DC-DC SSRs (40A for PTC/fan, 10A for motors),
> and Mega PWM for AVC blowers.
>
> staged operation mandatory; LCD I2C on Mega pins 20/21.

---

## 1. System Overview

```mermaid
flowchart TB
    BAT["12V LiFePO4<br/>Battery<br/>1× 200Ah, BMS Protected"]

    BUS_POS["12V Positive Bus Bar<br/>(10-Terminal Copper)"]
    BUS_NEG["12V Negative Bus Bar<br/>(10-Terminal Copper)"]

    ST1["Station 1<br/>3x PTC + 3x Blowers + Motor"]
    ST2["Station 2<br/>3x PTC + 3x Blowers + Motor"]
    ST3["Station 3<br/>3x PTC + 3x Blowers + Motor"]
    FBUS["DC SSR (SSR-40DD)<br/>9x AVC Blower Power"]

    BUCK["LM2596S Buck<br/>12V to 5V"]
    MEGA["Arduino Mega 2560"]
    DHT["DHT22<br/>Ambient T/RH"]
    DS["DS18B20<br/>Heater T"]
    LCD["LCD 16x2<br/>I2C (pins 20/21)"]
    REED["Reed Switch<br/>Lid closed (D22)"]
    SOLN["Solenoid Lock SSR-10A<br/>(D23, fail-secure)"]

    BAT --> BUS_POS
    BAT --> BUS_NEG
    BUS_POS --> ST1
    BUS_POS --> ST2
    BUS_POS --> ST3
    BUS_POS --> FBUS
    BUS_POS --> BUCK --> MEGA
    DHT --> MEGA
    DS --> MEGA
    REED --> MEGA
    MEGA --> SOLN
    MEGA <--> LCD
    MEGA -. "D4/D6/D8<br/>DC SSR (SSR-40DD)" .-> ST1
    MEGA -. "D4/D6/D8<br/>DC SSR (SSR-40DD)" .-> ST2
    MEGA -. "D4/D6/D8<br/>DC SSR (SSR-40DD)" .-> ST3
    MEGA -. "D13 DC SSR (SSR-40DD)" .-> FBUS
    MEGA -. "D5/D7/D9<br/>DC SSR (SSR-10A)" .-> ST1
    MEGA -. "D5/D7/D9<br/>DC SSR (SSR-10A)" .-> ST2
    MEGA -. "D5/D7/D9<br/>DC SSR (SSR-10A)" .-> ST3
    MEGA -. "D10/D11/D12<br/>PWM (analogWrite)" .-> FBUS
    ST1 -. "GND Return" .-> BUS_NEG
    ST2 -. "GND Return" .-> BUS_NEG
    ST3 -. "GND Return" .-> BUS_NEG
    FBUS -. "GND Return" .-> BUS_NEG
    MEGA -. "GND Return" .-> BUS_NEG
```

---

## 2. Power Distribution Tree

```mermaid
flowchart TB
    BAT["12V LiFePO4<br/>Battery"]
    BUS["12V Positive Bus Bar<br/>(10-Terminal Copper)"]

    subgraph STA["STATION BRANCH - x3 IDENTICAL"]
        direction TB
        SSR_H["DC SSR (SSR-40DD)<br/>Input: Mega pin<br/>Output: PTC heaters"]
        PTC["3× PTC Heater<br/>12V 100W each<br/>Parallel: 300W"]
        SSR_M["DC SSR (SSR-10A)<br/>Input: Mega pin<br/>Output: Motor"]
        MOT["SGM-370<br/>Worm Motor"]
    end

    subgraph FANBUS["AVC BLOWER BUS"]
        direction TB
        SSR_F["DC SSR (SSR-40DD)<br/>Input: Mega D13<br/>Output: 9 blowers"]
        BLOW["9× AVC Blower<br/>12V 4.5A each<br/>PWM via D10/D11/D12"]
    end

    subgraph LOGIC["LOGIC FEED"]
        direction TB
        BUCK["LM2596S Buck<br/>12V to 5V"]
        MEGA["Arduino Mega 2560"]
    end

    BAT --> BUS
    BUS --> SSR_H --> PTC
    BUS --> SSR_M --> MOT
    BUS --> SSR_F --> BLOW
    BUS --> BUCK --> MEGA
```

---

## 3. Per-Station Architecture

One drying station in full detail. All three stations are electrically identical.

```mermaid
flowchart TB
    SSR_PTC["DC SSR (SSR-40DD)<br/>Input +: Mega D4/D6/D8<br/>Input −: GND<br/>Output: from 12V bus"]

    subgraph HEATERS["PTC Heater Array - 300W"]
        H1["PTC 1<br/>12V 100W"]
        H2["PTC 2<br/>12V 100W"]
        H3["PTC 3<br/>12V 100W"]
    end

    SSR_PTC --> H1 & H2 & H3

    SSR_MOT["DC SSR (SSR-10A)<br/>Input: Mega D5/D7/D9<br/>Input −: GND<br/>Output: to motor +"]

    MOTOR["SGM-370<br/>12V 6RPM<br/>Motor − to GND"]

    subgraph BLOWERS["AVC Blowers ×3 (parallel)"]
        BLOW_SIG["PWM signal<br/>from Mega D10/D11/D12"]
        BLOW_PWR["12V power<br/>from fan bus SSR"]
        BLOW_FAN["80mm AVC<br/>12V 4.5A blowers"]
    end

    SSR_MOT --> MOTOR
    MOTOR -. "− lead" .-> GND["Common GND"]

    BLOWERS
    BLOW_PWR -->|\"from D13 fan SSR\"| BLOW_SIG --> BLOW_FAN
```

---

## 4. Controller I/O Map — Arduino Mega 2560

```mermaid
flowchart LR
    subgraph IN["SENSOR INPUTS"]
        DHT["DHT22<br/>Data: D2<br/>10kΩ pull-up"]
        DS["DS18B20<br/>Data: D3<br/>4.7kΩ pull-up"]
        REED["Reed switch<br/>Lid closed: D22<br/>INPUT_PULLUP"]
    end

    MEGA["Arduino Mega 2560<br/>ATmega2560 16MHz<br/>5V from LM2596S buck<br/>I2C on pins 20/21"]

    subgraph I2C["I2C BUS"]
        LCD["LCD 16x2<br/>SDA: D20<br/>SCL: D21"]
    end

    subgraph PTC_OUT["PTC HEATER SSRs (SSR-40DD, DC output, active-HIGH)"]
        R1["D4: Station 1 PTC<br/>(~25A)"]
        R2["D6: Station 2 PTC<br/>(~25A)"]
        R3["D8: Station 3 PTC<br/>(~25A)"]
    end

    subgraph MOT_OUT["MOTOR SSRs (SSR-10A, active-HIGH)"]
        M1["D5: Station 1 motor<br/>(~0.8A)"]
        M2["D7: Station 2 motor<br/>(~0.8A)"]
        M3["D9: Station 3 motor<br/>(~0.8A)"]
    end

    subgraph FAN_OUT["FAN BUS + BLower PWM"]
        FB["D13: Fan bus SSR<br/>(SSR-40DD, active-HIGH)"]
        E1["D10: PWM Station 1 blowers<br/>analogWrite(D10, val)"]
        E2["D11: PWM Station 2 blowers<br/>analogWrite(D11, val)"]
        E3["D12: PWM Station 3 blowers<br/>analogWrite(D12, val)"]
    end

    subgraph UI_OUT["UI OUTPUTS"]
        BTN["D14: Button<br/>(INPUT_PULLUP, LOW=ON)"]
        LED_R["D15: Red LED"]
        LED_Y["D16: Yellow LED"]
        LED_G["D17: Green LED"]
        BUZ["D18: Buzzer"]
    end

    subgraph LID_OUT["LID INTERLOCK"]
        SOLN["D23: Solenoid lock SSR-10A<br/>(fail-secure; ~3 s pulse = unlock)"]
    end

    DHT --> MEGA
    DS --> MEGA
    REED --> MEGA
    MEGA <--> LCD
    MEGA --> PTC_OUT
    MEGA --> MOT_OUT
    MEGA --> FAN_OUT
    MEGA --> UI_OUT
    MEGA --> LID_OUT
```

---

## 5. Wire Schedule

| Path | Wire Gauge | Notes |
|---|---|---|
| Battery to bus | 8 AWG | Direct connection |
| Station 1 PTC branch | 10 AWG | 3× PTC heaters via SSR |
| Station 2 PTC branch | 10 AWG | 3× PTC heaters via SSR |
| Station 3 PTC branch | 10 AWG | 3× PTC heaters via SSR |
| Station 1 Motor branch | 18 AWG | SGM-370 via SSR-10A |
| Station 2 Motor branch | 18 AWG | SGM-370 via SSR-10A |
| Station 3 Motor branch | 18 AWG | SGM-370 via SSR-10A |
| AVC blower bus | 10 AWG | 9 blowers, 18 AWG pigtails |
| Lid solenoid lock branch | 20 AWG | SSR-10A (D23) → solenoid lock |
| Logic feed | 20 AWG | Buck converter input |
| Buck to Mega | 20 AWG | 5V regulated rail |
| BLOWER signal wires | 22 AWG | PWM from Mega (D10–D12) |

## 6. Wire Gauge Rationale

| Run | Gauge | Rationale |
|---|---|---|
| Battery main + main links | 8 AWG | 200A BMS peak, <3% drop |
| Station PTC + blower branches | 10 AWG | 40A, short runs |
| Motor branches | 18 AWG | <1A |
| Logic feed | 20 AWG | <0.5A |
| Signal / LED / buzzer jumpers | 22 AWG | Logic-level only |

## 7. Design Notes

1. **Staged operation is mandatory.** One station draws ~39.3A (3 PTC + 3 blowers + motor + logic); two stations ≈ 78.6A. The BMS is rated 200A, so this is not a fuse limitation — staged operation preserves battery/BMS current budget and follows the study's energy-efficient control strategy. Firmware enforces one station at a time with 30s rotation.
2. **PTC self-limiting.** PTC elements reduce current as temperature rises. Inrush is brief; steady-state per station ~15–20A.
3. **No mains voltage anywhere.** Entire system is 12V DC SELV.
4. **PTC heaters and fan bus are switched by SSR-40DD solid-state relays** (input 3–32VDC, DC output, 40A rated). Driven directly from Mega digital pins — no NPN transistors, no base resistors, no flyback diodes needed. Active HIGH = ON; no input current = OFF (boot-safe).
5. **Motor SSRs are LCTC DC-DC SSR-10A** (DC output, active-HIGH). Direct drive from Mega pins — no optocoupler module needed. Active HIGH = ON; floating pin = OFF at boot.
6. **AVC blowers are PWM-controlled directly from Mega** (D10/D11/D12) using `analogWrite()`. No ESC needed. 5V logic compatible.
7. **No thermal fuses.** Over-temperature protection relies on PTC self-regulation and DS18B20 firmware 65 °C cutoff. Over-current protection relies on BMS 200A cutoff and PTC self-regulation. There is no hardware fuse backstop.
8. **Fan bus SSR (D13)** must be ON for blowers to receive 12V power. The PWM signal (D10/D11/D12) controls speed independently.
9. **LCD I2C is on Mega pins 20/21** (hardware I2C) — NOT A4/A5 (which are ADC on the Mega).
10. **Lid safety interlock:** reed switch (D22) prevents a start while the lid is open; a fail-secure solenoid lock (D23 via SSR-10A) holds the lid shut for the whole cycle and is pulsed open only at COMPLETE / on a 2 s hold to load.

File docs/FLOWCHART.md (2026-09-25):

# Flowcharts — Control Loop & Safety Interlocks — 12V DC

> Firmware behavior reference. Pin assignments per `wiring/README.md`; state machine per `docs/FIRMWARE-GUIDE.md`.

---

## 1. Main control loop

```mermaid
flowchart TD
    PWR([Power on]) --> INIT["Init: all SSRs LOW<br/>blower PWM 0 (D10–D12)<br/>LCD hello, sensor probe"]
    INIT --> SELF{Self-test pass?<br/>DHT22 + DS18B20 valid}
    SELF -- no --> FAULT["FAULT state<br/>red LED + long beeps"]
    SELF -- yes --> IDLE["IDLE<br/>green LED<br/>All loads OFF<br/>LCD: READY"]

    IDLE -- "hold 2s" --> UNLID["UNLOCK LID<br/>(solenoid pulse ~3 s)<br/>open + load"]
    UNLID --> IDLE

    IDLE -- "tap Start (D14)" --> LIDCLOSED{Lid closed?<br/>reed D22 = LOW}
    LIDCLOSED -- no --> REFUSE["START BLOCKED<br/>buzzer + CLOSE LID"]
    REFUSE --> IDLE
    LIDCLOSED -- yes --> PREHEAT["PREHEAT<br/>red LED<br/>Lid LOCKED (solenoid off)<br/>Fan bus ON (D13)<br/>Blowers FULL (D10–D12)<br/>PTC ON for station 1 (D4)<br/>Staged: rotate 30s"]

    PREHEAT --> READ["Read DHT22 humidity<br/>read DS18B20 temp"]
    READ --> TOVER{T > 65°C?}
    TOVER -- yes --> CUTOFF["THERMAL CUTOFF<br/>ALL OFF<br/>red LED blink + error on LCD"]
    TOVER -- no --> TEMP_OK{T ≥ 45°C?}
    TEMP_OK -- no --> PREHEAT
    TEMP_OK -- yes --> DRY["DRY<br/>yellow LED<br/>PTC + motor ON<br/>Staged: rotate 30s<br/>15 min timer"]

    DRY --> READ2["Read sensors"]
    READ2 --> TOVER2{T > 65°C?}
    TOVER2 -- yes --> CUTOFF
    TOVER2 -- no --> RH{RH ≤ 60%?<br/>after ≥ 3 min drying}
    RH -- yes --> COOL["COOL<br/>PTC OFF, motor OFF<br/>Blowers stay ON<br/>2 min timer"]
    RH -- no --> TIMER{15 min done?}
    TIMER -- no --> DRY
    TIMER -- yes --> COOL

    COOL --> COOL_TIMER{2 min done?}
    COOL_TIMER -- no --> COOL
    COOL_TIMER -- yes --> DONE["COMPLETE<br/>All OFF<br/>green LED + 3 beeps"]
    DONE --> IDLE

    FAULT --> IDLE
    CUTOFF --> IDLE
```

---

## 2. Safety interlock (inner loop, runs every 500ms)

```mermaid
flowchart TD
    TICK([Control tick]) --> T1{DS18B20 read OK?}
    T1 -- "fail x3" --> SERR["Sensor fault → FAULT"]
    T1 -- ok --> T2{T > 65°C?}
    T2 -- yes --> OFF1["ALL OFF<br/>PTC SSRs LOW (D4/D6/D8)<br/>Motor SSRs LOW (D5/D7/D9)<br/>Fan bus SSR LOW (D13)<br/>Blower PWM 0 (D10–D12)"]
    T2 -- no --> T3{Cycle active?}
    T3 -- no --> OFF2["All actuators OFF"]
    T3 -- yes --> OK["System OK — continue phase"]

    OFF1 --> WRITE["Write pins D4–D18"]
    OFF2 --> WRITE
    OK --> WRITE
    SERR --> WRITE
```

> **Defense in depth:** DS18B20 firmware cutoff (65°C) → PTC self-regulation → BMS 200A. Three independent layers.
>
> **Energy-efficient control:** DRY exits early once chamber RH ≤ 60% (min 3 min drying) — the study's humidity-based control.

---

## 3. Per-station fault handling

```mermaid
flowchart TD
    RUN(["Station n running"]) --> JAM{Umbrella jammed?<br/>stall noise}
    JAM -- yes --> STALL["Motor stalls<br/>SGM-370 stall current ~0.8A<br/>self-locking worm holds the load"]
    STALL --> USER["User clears the jam<br/>restarts the cycle"]
    USER --> RUN
    JAM -- no --> RUN
```

> **Design note:** stations are not sensor-monitored (no current-sense path). A stalled motor is detected by ear — hum without rotation — see `docs/TROUBLESHOOTING.md`.

---

## 4. Fan control on boot

No ESC arming needed — blowers take duty-cycle PWM directly from Mega pins.

```mermaid
flowchart LR
    BOOT([Boot]) --> SAFE["All SSRs LOW<br/>PWM pins 0 (D10–D12)"]
    SAFE --> IDLE["IDLE<br/>blowers off until PREHEAT"]
```

---

## 5. State summary

| State | PTC SSRs | Motor SSRs | Fan Bus + Blower PWM | LED | Buzzer | Lid lock |
|---|---|---|---|---|---|---|
| IDLE | OFF | OFF | OFF | Green | — | LOCKED (unlock = hold 2 s) |
| PREHEAT | Staged (1 at a time) | OFF | ON (full speed) | Red | — | LOCKED |
| DRY | Staged (1 at a time) | Staged (1 at a time) | ON (full speed) | Yellow | — | LOCKED |
| DRY (auto-stop) | → COOL | → COOL | → COOL | Yellow | — | LOCKED |
| COOL | OFF | OFF | ON (full speed) | Yellow | — | LOCKED |
| COMPLETE | OFF | OFF | OFF | Green | 3 beeps | **UNLOCKED** (pulsed open) |
| THERMAL CUTOFF | OFF | OFF | OFF | Red (blink) | 1 chirp (on failed reset) | LOCKED |
| FAULT | OFF | OFF | OFF | Red | long beeps | LOCKED |

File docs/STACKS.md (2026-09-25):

# Stack — 12V DC

> Quick-reference card for the full hardware + software stack.

---

## Hardware layers

| Layer | Components |
|---|---|
| Power | 1× LiFePO4 200Ah → 50A DC rocker switch → 2-pin screw terminal → 150A bus bars → SSR branches (no fuses) |
| Conversion | LM2596S buck: 12V → 5V for Mega (5V pin only) |
| Actuation | 3× PTC heater groups (LCTC DC-DC SSR 40A), 9× AVC blowers (direct PWM D10–D12 + SSR-40DD fan bus), 3× worm motors (LCTC DC-DC SSR 10A), **lid solenoid lock (SSR-10A D23)** |
| Thermal protection | PTC self-regulation, DS18B20 firmware cutoff |
| Sensing | DHT22 (humidity), DS18B20 (temperature), **lid reed switch (D22)** |
| Safety interlock | **Lid-closed reed (won't start if open) + fail-secure solenoid lock (locked for the whole cycle)** |
| Control | Arduino Mega 2560 |
| UI | 16×2 LCD I2C (pins 20/21), 3× LEDs (D15–D17), buzzer (D18), arcade button (D14) |
| Drivetrain | 3× SGM-370 → rigid coupling 6×8mm → 6mm × 300mm SS shaft on UCP06 pillow block → PETIYOUZA 6mm flange coupling → umbrella hub |

---

## Software stack

| Library | Purpose |
|---|---|
| DHT | Humidity from DHT22 |
| OneWire + DallasTemperature | Temperature from DS18B20 |
| LiquidCrystal_I2C | LCD display (Mega pins 20/21) |
| Main sketch | State machine (IDLE → PREHEAT → DRY → COOL → DONE), staged SSR control, blower PWM (`analogWrite`), thermal cutoff |

No Servo library needed — blowers take duty-cycle PWM straight from Mega pins.

---

## BOM summary

| Layer | Price (est.) |
|---|---|
| PTC heaters (9×₱1,162) | ≈ ₱10,460 |
| AVC blowers (9×₱330) | ≈ ₱2,970 |
| Motors + drivetrain (3× SGM-370 + couplings + shafts + pillow blocks + plate) | ≈ ₱3,892 |
| taxnele SSR 40A (4×) + SSR 10A (4×) + heatsinks | ≈ ₱2,270 |
| Control electronics (Mega, sensors, LCD, buck, resistors) | ≈ ₱1,314 |
| Lid safety interlock (reed switch + solenoid lock + 1N4007) | ≈ ₱480 |
| Battery (1× 200Ah) + charger | ≈ ₱11,700–12,200 |
| UI (LEDs, buzzer, button) | ≈ ₱109 |
| Wiring + consumables | ≈ ₱2,400 |
| DC Rocker Switch 50A | ~₱190 |
| **Total** | **≈ ₱35,800** |

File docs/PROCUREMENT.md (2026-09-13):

# PROCUREMENT — Verified Component Sourcing (Lazada PH)

> **Annex to [`docs/BOM.md`](BOM.md) §14** — this file carries the per-listing detail: backup listings, seller ratings and reasoning, and watch-outs. The consolidated order cart lives in BOM.md Appendix A.

**Project:** Smart Umbrella Dryer (PUP Santa Maria, BS CpE capstone)
**Sourcing policy:** Makerlab PH first — verified trusted Lazada store (98% seller rating, 845.6K items sold, 10-Year Store, Bulacan). Items Makerlab doesn't carry → trusted third-party sellers with high rating/sold counts only.
**Prices verified:** 2026-09-12 (Lazada prices move — re-check before ordering)
**Rev 5 quantities:** 3× worm gear motors (one per umbrella station) · **2× Fotek SSR-40DA (AC output — mains heaters)** + 2× 2-CH relay modules · **2× 1500W 220V PTC heater-fans + 12" Omni exhaust fan** · mains kit (RCD, grounded box, 10A fuses, 2.0mm² wire) · 3× shafts / bearing sets / couplings · 25A DC main fuse · MLX90614 removed.

##  All components sourced

### Controller & drivers

**Arduino Mega 2560 R3 — ₱1,215 (Makerlab PH)**
- Listing: Mega 2560 R3 Board based on Arduino® | 4.8 (331) | 2.4K sold
- URL: https://www.lazada.com.ph/products/pdp-i5989151.html
- Variant: ₱1,215 = "no cable" · ₱1,265 = with USB cable

**LM2596S Buck Converter w/ 7-seg display — ₱155 (Makerlab PH)**
- Listing: DC-DC Buck Converter with 7 Segment Display LM2596S | 4.8 (264) | 1.3K sold
- URL: https://www.lazada.com.ph/products/pdp-i127879071.html
- Backup (plain, ₱49, 4.8 (494), 4.5K sold): https://www.lazada.com.ph/products/pdp-i6005010.html

### Heater & power path

**2-Channel Relay Module 5V w/ optocoupler, low-level trigger — ₱89 ea ×2 (3 motor stations)**
- Listing: 2 Channel Relay Module 5V Optocoupler Low Level Trigger | (330) | 2.5K sold | Bulacan
- URL: https://www.lazada.com.ph/products/pdp-i100047444.html
- Qty 2 → 4 channels: 3 worm-motor stations (1 ch each) + 1 spare. Coils fed from the LM2596S 5V rail; Mega drives only the optocoupler LEDs.
- Rev 5 note: the 1-CH 30A relay and the 12V PTC heater that used to sit here are **removed** — heaters moved to mains AC via 2× SSR-40DA (see the Mains AC kit section above).

### Heaters & airflow (Rev 5)

**(moved to the Mains AC kit section above — the 120mm 12V fan is no longer used; replaced by the Omni 12-inch exhaust fan)**

**LiFePO4 Battery 12.8V 30Ah w/ BMS (PowMr)**  pre-order flag
- Listing: PowMr 12.8V 30AH LiFePO4 Battery Built-in BMS | 152.9K store sold
- URL: https://www.lazada.com.ph/products/pdp-i4660631878.html
- PDP-verified: **LiFePO4 chemistry, 12.8V, 30Ah, BMS** . ExpertPower 35Ah (paper's choice) is NOT on Lazada PH — this PowMr 30Ah is the best local equivalent (spec re-check: 30Ah = ~4 cycles/charge instead of 5).
-  Price varies by promo — check PDP. Scout noted a **pre-order / ship-in-60-days flag** — confirm stock before committing, or order early.

**Blade fuses + holder — ₱122.53 + ₱25**
- Fuses: 100pcs Car Blade Fuse Assortment 2-35A w/ box | 4.9 (5022) | 14.3K sold — needs **25A DC main, 3A ×3 motor stations, 3A logic** (mains 10A fuses come from the AC box kit) — https://www.lazada.com.ph/products/pdp-i4214903852.html
- Holder: 1× Panel-Mount Fuse Holder | ₱25 · 131 sold · (13) · Bulacan (Makerlab listing) — https://www.lazada.com.ph/products/pdp-i2502994973.html — for the 25A DC main; motor-branch 3A fuses use inline holders from the assortment.

**Rocker Switch 16A — ₱72 (Unnicoco, 97%)**  DC derating
- Listing: Unnicoco 16A 250VAC / 20A 125VAC Rocker Switch 4 Pins | 111.4K store sold
- URL: https://www.lazada.com.ph/products/pdp-i2272943066.html
-  Rating is AC. At 12V DC, arcing is worse — derate ~50%. **Recommended wiring: rocker switches the control side (buck input + relay coils), NOT the full battery load.** The AC mains rocker is a separate 2-gang part from the hardware kit.

### Mains AC kit (Rev 5)

**2× 1500W PTC industrial heater-fan, 220V — ₱1,395.35 ea**
- Listing: Portable Industrial Electric Heater Fan Commercial Thermostat Air Warm Heater Blower
- URL: https://www.lazada.com.ph/products/portable-industrial-electric-heater-fan-commercial-thermostat-air-warm-heater-blower-radiator-office-garage-air-fan-i4902069326-s2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
- Switched by SSR-40DA each; keep built-in thermostat + thermal cutoff in circuit; plug accessible.

**Omni industrial exhaust fan w/ grill, wall-mount — ~₱1,000–1,500 (verify variant)**
- Listing: Omni Industrial Exhaust Fan W/ Grill Wall Mounted | spans 12/14/16-inch
- URL: https://www.lazada.com.ph/products/omni-industrial-exhaust-fan-w-grill-wall-mounted-12-inch-14-inch-16-inch-i4020672066-s21738898500.html
- ⚠️ **Select the 12-inch variant.** Runs on its own mains rocker gang — no SSR.

**Fotek SSR-40DA ×2 — ₱850 ea (makerlab.ph)**
- 3–32VDC input, 24–380VAC output, 40A. ⚠️ MUST be **DA** (AC output) for these 220V heaters — the DD type cannot switch AC loads. Heatsink mandatory (7–10W each).
- URL: https://makerlab.ph/products/original-solid-state-relay-ssr-40da-ssr-75da-ssr-25dd-4-32v-dc-input

**Hardware-store additions (EST, add at checkout):** RCD/GFCI 30mA outlet or breaker · grounded metal electrical box · 2-gang mains rocker + plate · 2.0mm² 3-core wire + plug/socket set · 2× SSR heatsink profiles.

### Sensors

**DHT22 Temp/Humidity Sensor — ₱69 (FU-LABS, 98%)**
- Listing: DHT11/DHT22 Digital Temperature and Humidity Sensor | 5.0 (34) | 549 sold
- URL: https://www.lazada.com.ph/products/pdp-i4888079786.html
- Variant: **"DHT22 Black" module = ₱69** (default PDP shows ₱239 bare-probe variant). Makerlab website also sells DHT22 (₱200) — FU-LABS module is cheaper.

**DS18B20 Waterproof Sensor — ₱105 (Circuitrocks)**
- Listing: Waterproof One Wire Sensor DS18B20 3 Meters | (24) | 325 sold | Metro Manila
- URL: https://www.lazada.com.ph/products/pdp-i111662523.html
- Backup (1m kit ₱83.80): https://www.lazada.com.ph/products/pdp-i4824120037.html

### UI & indicators

**16×2 LCD with I2C — ₱165 (Makerlab PH)**
- Listing: 1602 16x2 Character LCD Module HD44780 with I2C | 4.9 (681) | 5.8K sold
- URL: https://www.lazada.com.ph/products/pdp-i104139284.html
- Backup (plain LCD no I2C ₱105): https://www.lazada.com.ph/products/pdp-i156791905.html

**Push Buttons 12mm ×10 — ₱79 (Makerlab PH)**
- Listing: 10pcs 12mm Round Button Tactile Switch | 4.9 (92) | Makerlab store
- URL: https://www.lazada.com.ph/products/pdp-i118682689.html

**5mm LED Kit (10pc multi-color) — ₱29**
- Listing: 10Pcs 5mm Led Kit Red Green Yellow Blue White | (433) | 3.0K sold | Bulacan
- URL: https://www.lazada.com.ph/products/pdp-i3105641040.html

**Active Buzzer Module — ₱35 (Makerlab PH)**
- Listing: Active Alarm Buzzer Driver Module High Current | 4.9 (78) | 537 sold
- URL: https://www.lazada.com.ph/products/pdp-i3474748260.html
- Backup (piezo 3-24V ₱55): https://www.lazada.com.ph/products/pdp-i2270182027.html

### Drivetrain & mechanicals

**Worm Gear Motor 12V — Makerlab website ₱1,249 ×3 — one per umbrella station** (primary)
- Makerlab.ph: DC Worm Gear Motor SGM-A58SW31ZYS 12V 16/80RPM (60 kg·cm class, self-locking) — confirmed NOT on their Lazada store, order from makerlab.ph.
- **Rev 4: qty 3 — put all three in one makerlab.ph order.**
- The Lazada JGY370 (~25 kg·cm, different shaft size) is NOT an acceptable substitute at any quantity.

**8mm Steel Shaft — 304 SS ground rod (₱222.40+) — qty 3, one per station**
- Primary: 304 Stainless Steel Rod 6/7/8/10mm Linear Shaft Ground Stock 300/500/1000mm — **8mm × 300mm variant** | 370 sold | (80) — https://www.lazada.com.ph/products/pdp-i5154908354.html
- Alternate (price-verified ₱222.40, 28% off, 77 sold, (19)): https://www.lazada.com.ph/products/pdp-i4473127402.html

**KP08 Pillow Block Bearings — ₱310 per 2-pc set, qty 3 sets = 6 bearings (2 per station)**
- Listing: 2 pcs Pillow Block Bearing KP08 KP000-KP003 8mm-20mm | (44) | 286 sold | Bulacan
- URL: https://www.lazada.com.ph/products/pdp-i5039609084.html
- Variant: **select KP08 (8mm bore)** — listing spans KP08-KP004.
- Single-unit backups: zinc KP08 ₱49-87, 311 sold, QC — https://www.lazada.com.ph/products/pdp-i4139708194.html

**Shaft Coupling (incl. 8×8) — ₱82.84 (FUXING)**
- Listing: 1set Rigid Shaft Coupling 4/5/6/8/10mm Motor Connector Sleeve #45 Steel | (185) | 408 sold
- URL: https://www.lazada.com.ph/products/pdp-i2734273953.html
- Set includes 8mm — clamp-style rigid sleeve. Use the 8×8 config for motor-to-shaft. **Qty 2 sets** (3× 8×8 configs needed + spare).

##  Watch-outs (read before ordering)

1. **Relay contacts are 30VDC-rated** — never on mains AC; heater uses slow duty cycling only (2–5s period).
2. **Heater wattage:** only 70W/100W 12V PTC variants exist on Lazada — no 120W. Plan around 100W (cycle ~20% longer than the 120W math).
3. **Battery lead time:** PowMr 30Ah flagged pre-order (~60 days). Order FIRST or find local stock. 30Ah ≈ 3–4 cycles/charge with 3 motor stations.
4. **Rocker DC derating:** don't push a 16A AC-rated switch on the battery load — switch the control side instead.
5. **Motor torque:** the JGY370 Lazada listing is ~25 kg·cm — under the 60 kg·cm spec. Makerlab's SGM-A58SW31ZYS (site-only, qty 3) is the spec-correct choice.

## One-stop alternatives

Makerlab.ph website (not Lazada) also carries: DHT22 (₱200), DS18B20 (₱99), LCD 1602 (plain ₱105 / I2C versions), fuse holders, KCD11 rockers (3A — too small for main switch), SGM worm motors (order all ×3 here), couplings. If you want fewer shipments, order the Makerlab-website-only items there and the rest from their Lazada store.

**Shopee PH not checked** (login-walled for automated verification). All listings above are Lazada PH.

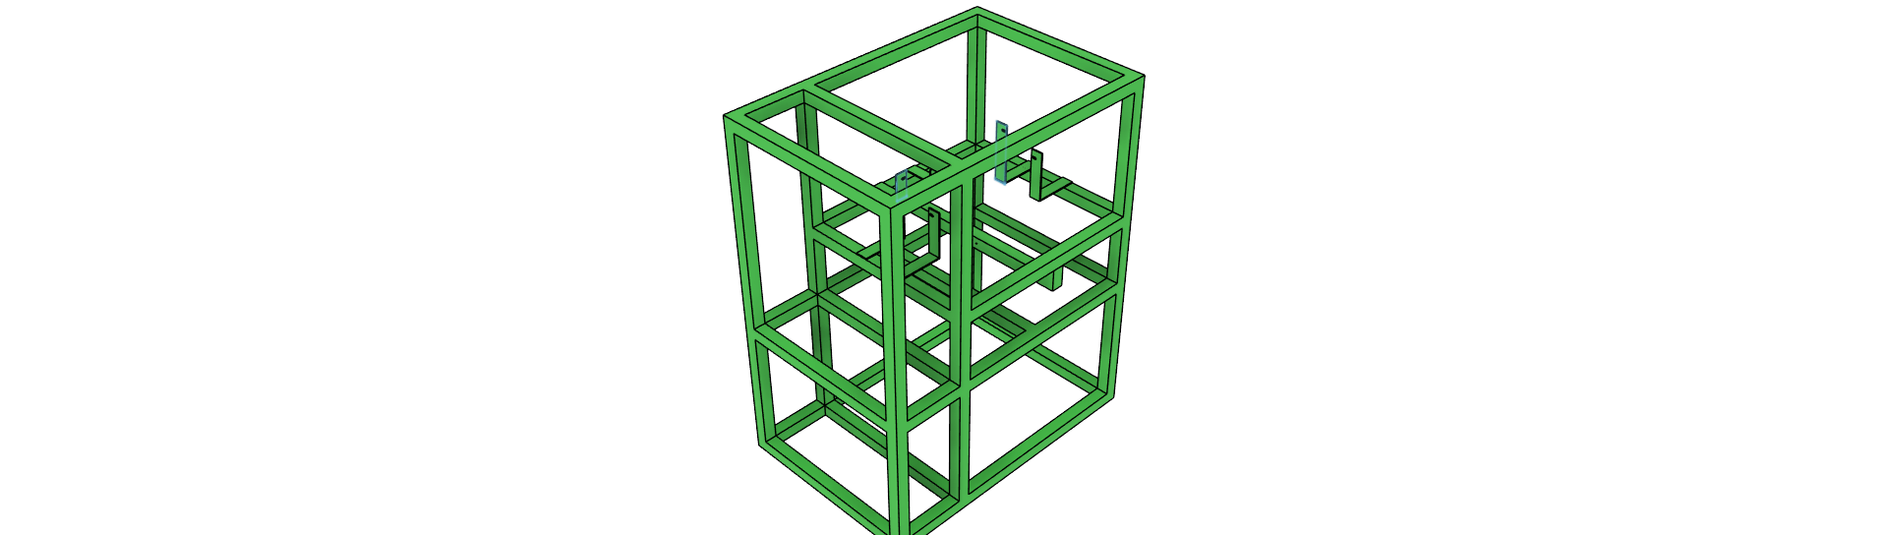
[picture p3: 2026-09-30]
model/Chassis.png

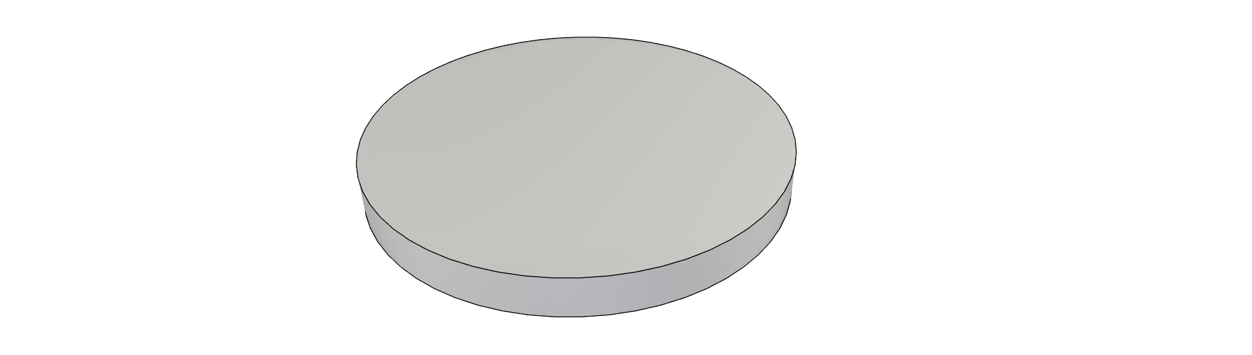
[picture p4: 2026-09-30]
model/Plate.png

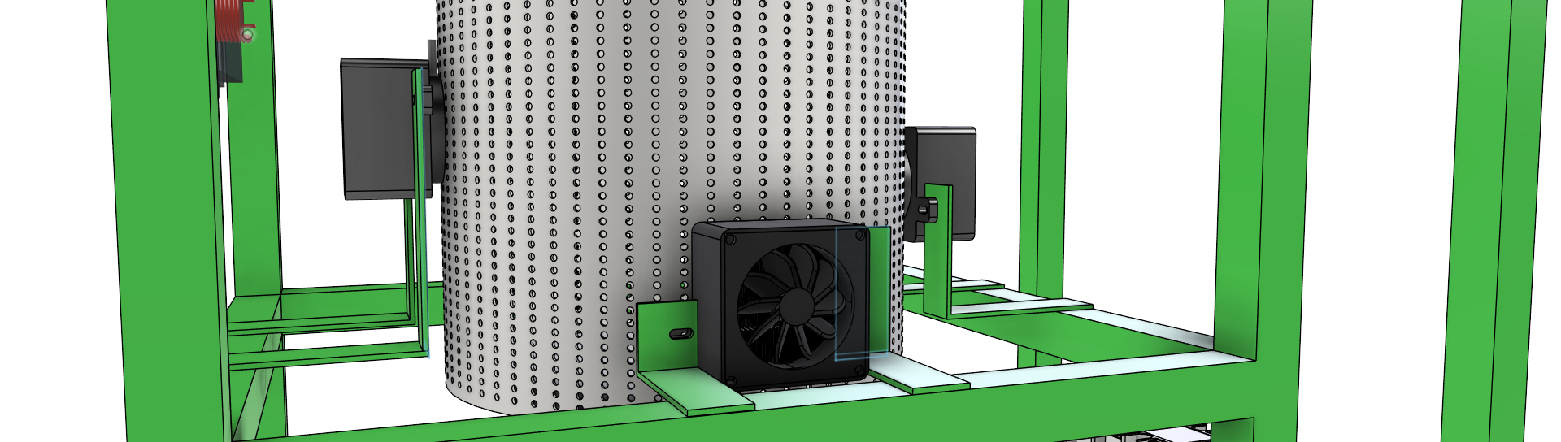
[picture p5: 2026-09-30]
model/UmbrellaDryerV2_15.png

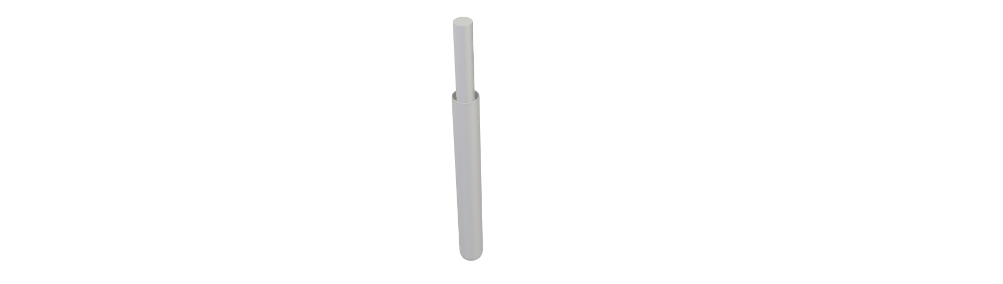
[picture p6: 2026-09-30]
model/DS18B20.png

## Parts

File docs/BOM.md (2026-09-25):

# Umbrella Dryer V2 — Bill of Materials

> Design: 12V DC-only system. Each umbrella station has 3× PTC heaters (100W each), 3× AVC 12V 4.5A blowers (PWM-controlled directly from Mega), and 1× worm gear motor. Battery-powered with **1× 200Ah LiFePO4**. **DC-output SSR-40DD** control PTC heaters (direct-drive from Mega), **LCTC DC-DC SSR 10A** (×4) control the worm motors **and the lid solenoid lock** (replaces optocoupler module), **Mega PWM** controls AVC blowers. A **reed switch + solenoid lock lid safety interlock** prevents starting with the lid open and locks the lid for the whole cycle.

---

## 1. Control (logic)

| Qty | Part | Notes | Price | Source |
|---|---|---|---|---|
| 1 | Arduino Mega 2560 + USB cable | CH340G — Makerlab PH | ₱1,165 | Lazada — Makerlab PH |
| 1 | DHT22 temperature + humidity sensor module | Mount mid-chamber, away from air jets | ₱210 | Lazada — Makerlab PH |
| 1 | DS18B20 waterproof (probe + long lead) | Attached in heater airstream | ₱105 | Lazada |
| 1 | 16×2 LCD I2C (black on white OK) | I2C address 0x27 or 0x3F; **wire to Mega pins 20/21** | ₱165 | Lazada |

---

## 2. Power conversion — 12V DC

| Qty | Part | Notes | Price |
|---|---|---|---|
| 1 | LM2596S DC-DC buck converter | 12V→5V for Mega + sensors; **set to 5.00 V before connecting to Mega 5V pin** | ₱49 |

---

## 3. Power supply — 12V DC

### 3a. Battery bank + charging

| Qty | Part | Notes | Price |
|---|---|---|---|
| 1 | **LiFePO4 12.8V 200Ah w/ BMS 200A (PowMr)** | Single battery, 200Ah, 2,560Wh; **ORDER FIRST** | ~₱8,900 |
| 1 | **LiFePO4 charger 14.6V 20A** | VariCore alligator clip; CC/CV; LED indicator; never lead-acid | ~₱2,809 |

### 3b. DC power distribution

| From | To | Wire | Protection |
|---|---|---|---|
| Battery + | 50A DC Rocker Switch | 8 AWG | Manual disconnect |
| Rocker Switch + | 2-pin screw terminal (battery in) | 8 AWG | — |
| Battery − | 12V Negative Ground Bus Bar | 8 AWG | — |

> **No fuses, no ANL breakers.** Main power controlled by 50A DC rocker switch. Emergency kill = flip rocker OFF + unplug battery cable.

> **Wire:** 8 AWG battery main, 10 AWG heater/fan branches, 18 AWG motor, 20 AWG logic, 22 AWG signals. All stranded copper. No fuses. Main power disconnected via 50A DC rocker switch.

### 3c. High-current switching (12V DC)

| Channel | Pin | SSR type | Load | Current | Active level |
|---|---|---|---|---|---|
| PTC Station 1 | D4 | LCTC DC-DC SSR 40A (DC output) | 3× PTC heaters | ~25A | HIGH = ON |
| Motor Station 1 | D5 | LCTC DC-DC SSR 10A (DC output) | SGM-370 | ~0.8A | HIGH = ON |
| PTC Station 2 | D6 | LCTC DC-DC SSR 40A (DC output) | 3× PTC heaters | ~25A | HIGH = ON |
| Motor Station 2 | D7 | LCTC DC-DC SSR 10A (DC output) | SGM-370 | ~0.8A | HIGH = ON |
| PTC Station 3 | D8 | LCTC DC-DC SSR 40A (DC output) | 3× PTC heaters | ~25A | HIGH = ON |
| Motor Station 3 | D9 | LCTC DC-DC SSR 10A (DC output) | SGM-370 | ~0.8A | HIGH = ON |
| Fan bus | D13 | LCTC DC-DC SSR 40A (DC output) | 9× AVC blowers | ~40.5A | HIGH = ON |
| Lid lock | D23 | LCTC DC-DC SSR 10A (DC output) | Solenoid lock | ~0.65A (pulsed) | HIGH = UNLOCK |

> **SSR direct drive:** All LCTC DC-DC SSR inputs connect directly to Mega pins. SSR input draws ≈10–20 mA at 5V — fine for direct drive. No additional components needed. Each SSR requires a heatsink (40A version: ~25W dissipation at 25A; fan bus at 40.5A: ~40W dissipation). Motor SSRs (10A): minimal dissipation at 0.8A.

### 3d. Fan PWM control — AVC blowers

| Channel | Pin | Function | Load | Speed control |
|---|---|---|---|---|
| Fans Station 1 | D10 | PWM signal | 3× AVC blowers (parallel) | `analogWrite(D10, val)` 0–255 |
| Fans Station 2 | D11 | PWM signal | 3× AVC blowers (parallel) | `analogWrite(D11, val)` 0–255 |
| Fans Station 3 | D12 | PWM signal | 3× AVC blowers (parallel) | `analogWrite(D12, val)` 0–255 |

> AVC blowers accept PWM duty cycle directly from Mega pins (5V logic). No ESC needed. Full speed = analogWrite(D, 255). Each blower draws 4.5A at full speed.

### 3e. Safety (12V DC)

- No fuses in the circuit
- DS18B20 cutoff if chamber exceeds 65 °C: firmware cuts all SSRs + blower PWM
- **Lid safety interlock:** firmware refuses to start while the lid is open (reed D22); the lid is locked shut for the whole cycle (solenoid D23, fail-secure) and only pulsed open at COMPLETE / on a 2 s hold to load
- PTC self-regulation: resistance rises with temperature, auto-limits
- Battery BMS protects against over-discharge, over-charge, short circuit
- No mains voltage anywhere — no RCD needed

---

## 4. Station peripherals

| Qty | Part | Notes | Price |
|---|---|---|---|
| 4 | Solid State Relay taxnele 40A (DC-DC) | SSR-40DD (3-32VDC input, 5-60VDC output); 3× PTC + 1× fan bus; direct-drive from Mega | ₱956.68 |
| 4 | Solid State Relay taxnele 10A (DC-DC) | SSR-10DD (3-32VDC input, 5-60VDC output); 3× motor + 1× lid solenoid | ₱872.88 |
| 4 | SSR Heatsink BLACK (80×50×50mm) | One per 40A SSR | ₱440 |
| 9 | AVC 12V DC blower fan | Super High Speed Blower, 80×80×38mm, PWM control, 4.5A each | ₱2,970 |
| 9 | 12V 100W PTC heater element (diymore) | Self-regulating ceramic — 3 per station | ₱10,459.80 |
| 1 | Screw terminal 2-pin | Battery in | ₱10 |
| 1 | Screw terminal 3-pin | Sensor | ₱10 |
| 1 | **Magnetic Door Reed Switch Set NO/NC (Makerlab PH)** | Lid-closed sensor (D22) — sends magnet included | ₱165 |
| 1 | **Solenoid Lock 12VDC (Makerlab PH)** | Lid bolt lock, fail-secure (D23 via SSR-10A) | ₱310 |
| 1 | 1N4007 diode | Flyback across solenoid — protects SSR output MOSFET | ~₱5 or scavenged |

---

## 5. Motor & Drive — 3× worm stations

3× SGM-370 12V 6RPM (14 kg·cm, ~0.2A rated / ~0.8A stall, 6mm output shaft, self-locking) — one per umbrella.

Mechanical (per station): **SGM-370 DC worm gear motor → rigid coupling (6×8mm) → 6mm × 300mm SS shaft → UCP06 pillow block (shaft passes through the bearing's middle) → PETIYOUZA rigid flange coupling (6mm bore) → umbrella hub.** Motor and pillow block bolted to the 6mm aluminum plate mount.

---

## 6. Thermal design (12V DC)

| Item | Spec |
|---|---|
| Heat source | 9× PTC ceramic heaters, 12V 100W each = 900W total (300W per station) |
| PTC behavior | Self-regulating: resistance rises with temperature → current drops → auto-limits |
| Heating method | PTC elements radiate + convect heat; AVC blowers circulate warm air |
| Temperature target | 40–60°C chamber air |
| Temperature sensing | DHT22 (humidity) mid-chamber + DS18B20 (temp) in heater airstream |
| Over-temperature | (1) DS18B20 firmware cutoff at 65°C (2) PTC self-regulation |
| Cooling | 3× AVC blowers per station; chamber is vented |

---

## 7. Capacity verification

### 7a. Mechanical — per-station torque — PASS
≤3 kg·cm per station vs 14 kg·cm → ≥4.6× margin; drivetrain: motor → rigid coupling → shaft through UCP06 pillow block → flange coupling to hub; 6 RPM gentle; self-locking hold.

### 7b. Thermal — PASS
300W per station with AVC blower circulation → 40–60°C chamber; DS18B20 + PTC self-regulation = dual over-temp protection.

### 7c. Electrical — 12V DC — PASS

| Subsystem | Voltage | Current (one station) | Protection |
|---|---|---|---|
| PTC heaters (3× 100W) | 12V | 25A | BMS 200A + PTC self-regulation |
| AVC blowers (3× 4.5A) | 12V | 13.5A | BMS 200A |
| Worm motor | 12V | 0.8A | BMS 200A |
| Mega + sensors | 5V | 0.1A | BMS 200A |
| **Total (one station)** | | **~39.3A** | **BMS 200A** |

### 7d. Battery runtime — 1× 200Ah LiFePO4

> **Usable capacity ≠ nameplate.** LiFePO4 should be cycled at 80% DoD for rated cycle
> life, and the battery should still meet spec at 90% capacity (end-of-life margin):
> **usable = 200 Ah × 0.80 × 0.90 ≈ 144 Ah** (≈ 1.73 kWh at 12V).

Load profile (staged, one station at a time):

| Phase | Draw | Notes |
|---|---|---|
| PREHEAT / DRY (active station) | ~39.3A | 3 PTC (25A) + 3 blowers (13.5A) + motor (0.8A) + logic (0.5A) |
| COOL | ~14A | Blowers (13.5A) + logic (0.5A) |
| Standby | ~0.5A | Sensors + LCD |

Energy per drying cycle (3 umbrellas per cycle):

| Cycle type | Duration | Energy | Per umbrella |
|---|---|---|---|
| Quick (surface dry, light rain) | 10 min preheat + 15 min dry + 2 min cool ≈ 27 min | ≈ 15 Ah (≈ 182 Wh) | ≈ 5 Ah |
| Standard (fully soaked) | 10 min preheat + 45 min dry + 2 min cool ≈ 57 min | ≈ 33 Ah (≈ 395 Wh) | ≈ 11 Ah |

> 45 min staged DRY gives each umbrella 15 min of direct heat — the same 300 W × 15 min
> dose as the original non-staged 15-min cycle.

**Runtime on the 200 Ah battery (144 Ah usable):**

| Mode | Result |
|---|---|
| Quick cycles | ≈ **9.6 cycles (~29 umbrellas)** per charge |
| Standard cycles | ≈ **4.4 cycles (~13 umbrellas)** per charge |
| Continuous staged operation | ≈ **3.7 hours** (144 Ah ÷ 39.3A) |
| Standby | ≈ 12 days (144 Ah ÷ 0.5A) |

**Capacity requirement vs daily scenarios:**

| Daily scenario | Ah/day | Min battery required (÷ 0.72) |
|---|---|---|
| Capstone demo: 6 quick cycles (18 umb) | ≈ 91 Ah | 126 Ah |
| Typical rainy day: 10 quick cycles (30 umb) | ≈ 151 Ah | 210 Ah |
| Typical rainy day: 8 standard cycles (24 umb) | ≈ 263 Ah | 365 Ah |
| Heavy day: 12 standard cycles (36 umb, full-dry) | ≈ 395 Ah | 548 Ah |

> **Verdict:** 1× 200Ah covers the capstone demo (18 umbrellas) with ~40% margin.
> For busy days, recharge between sessions — a full 0→100% recharge takes ~7–9 h at
> 14.6 V / 20 A (real-world CC/CV taper), or top up overnight.
> C-rate is gentle: 0.18 C at full staged draw, far below the 200A BMS limit.
>
> **Expansion path:** battery wiring supports adding a second 200Ah pack in parallel later (bank becomes 400Ah / 288 Ah usable) with no other changes.

---

## 8. Pin assignment (Mega 2560)

| Pin | Net | Direction | Function | Active level |
|---|---|---|---|---|
| D2 | DHT22_DATA | in | Chamber humidity + temp sensor | — |
| D3 | DS18B20_DATA | in | Heater-zone temperature probe | — |
| D4 | SSR_PTC_1 | out | PTC heaters station 1 (LCTC DC-DC SSR 40A) | HIGH = ON |
| D5 | SSR_MOTOR_1 | out | Worm motor station 1 (LCTC DC-DC SSR 10A) | HIGH = ON |
| D6 | SSR_PTC_2 | out | PTC heaters station 2 (LCTC DC-DC SSR 40A) | HIGH = ON |
| D7 | SSR_MOTOR_2 | out | Worm motor station 2 (LCTC DC-DC SSR 10A) | HIGH = ON |
| D8 | SSR_PTC_3 | out | PTC heaters station 3 (LCTC DC-DC SSR 40A) | HIGH = ON |
| D9 | SSR_MOTOR_3 | out | Worm motor station 3 (LCTC DC-DC SSR 10A) | HIGH = ON |
| D10 | PWM_FAN_1 | out (PWM) | Blower PWM — station 1 AVC blowers | — |
| D11 | PWM_FAN_2 | out (PWM) | Blower PWM — station 2 AVC blowers | — |
| D12 | PWM_FAN_3 | out (PWM) | Blower PWM — station 3 AVC blowers | — |
| D13 | SSR_FAN_BUS | out | Fan power bus (LCTC DC-DC SSR 40A) | HIGH = ON |
| D14 | BTN_START | in | Arcade push button (INPUT_PULLUP) | LOW = pressed |
| D15 | LED_RED | out | Heating active | HIGH = ON |
| D16 | LED_YELLOW | out | Cycle running / cooling | HIGH = ON |
| D17 | LED_GREEN | out | Ready / done | HIGH = ON |
| D18 | BUZZER | out | Audible notification | HIGH = ON |
| D22 | LID_REED | in | Lid closed sensor (NO reed) | LOW = LID CLOSED |
| D23 | SOL_LOCK | out | Lid solenoid lock (SSR-10A) | HIGH = UNLOCK (pulse ~3 s) |
| 20 | SDA | I2C | LCD data | — |
| 21 | SCL | I2C | LCD clock | — |

---

## 9. BOM line-item table (Lazada + makerlab)

| Qty | Part | Spec | Price | Seller | URL / note |
|---|---|---|---|---|---|
| 9 | PTC ceramic heater **diymore 12V 100W** | Self-regulating PTC ceramic, 12V 100W, ~6×4.2×6cm, 120g, mounting holes | ₱1,162.20 ea = ₱10,459.80 | Lazada — diymore | https://www.lazada.com.ph/products/diymore-dc-12v-100w-room-heater-energy-saving-ptc-car-air-fan-heater-constant-temperature-heating-heaters-factory-price-safe-home-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 (select **12V100W** variant) |
| 9 | **AVC 12V DC blower fan** | Super High Speed Blower, 80×80×38mm, PWM control, 4.5A | ₱330 ea = ₱2,970 | Lazada | https://www.lazada.com.ph/products/pdp-i2328323489.html |
| 3 | Worm gear motor SGM-370 | 12V 6RPM 14 kg·cm | ₱500 ea = ₱1,500 | makerlab.ph | https://makerlab.ph/products/dc-worm-gear-motor-sgm-370-12v-16rpm |
| 4 | Solid State Relay taxnele 40A (DC-DC) | SSR-40DD (3-32VDC input, 5-60VDC output) | ₱239.17 ea = ₱956.68 | Lazada | https://www.lazada.com.ph/products/pdp-i4110347574-s22718212255.html |
| 4 | SSR Heatsink BLACK (Makerlab) | BLACK 10A to 40A (Size: 80x50x50mm) | ₱110 ea = ₱440 | Lazada (Makerlab PH) | https://www.lazada.com.ph/products/ssr-heatsink-black-10a-to-40a-size80x50x50mm-ssr-heatsink-m-shape-small-type-heat-radiator-for-10a-to100a-size125x50x70mm-i3585835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 |
| 4 | Solid State Relay taxnele 10A (DC-DC) | SSR-10DD (3-32VDC input, 5-60VDC output); 3× motor + 1× lid solenoid | ₱218.22 ea = ₱872.88 | Lazada | https://www.lazada.com.ph/products/pdp-i4110347574-s22718212255.html |
| 1 | **Magnetic Door Reed Switch Set NO/NC (Makerlab PH)** | Lid-closed sensor (D22); NO contacts; magnet included | ₱165 | Lazada (Makerlab PH) | https://www.lazada.com.ph/products/pdp-i578584751-s1579814280.html |
| 1 | **Solenoid Lock 12VDC (Makerlab PH)** | Lid bolt lock, fail-secure; ~650 mA; pulse-only (D23 via SSR-10A). + 1N4007 flyback diode | ₱310 | Lazada (Makerlab PH) | https://www.lazada.com.ph/products/pdp-i109883946-s111626068.html |
| 1 | LM2596S Buck Converter (w/ display) | 12V→5V with 7-segment voltmeter display | ₱155 | Lazada (Makerlab PH) | https://www.lazada.com.ph/products/pdp-i127879071-s137114729.html |
| 1 | **Arduino Mega 2560 + Terminal Board** | CH340G + screw terminal board | ₱413 | Lazada | https://www.lazada.com.ph/products/mega-2560-16au-ch340g-based-on-arduino-arduino-mega-2560-terminal-board-i123143829-s20504057319.html |
| 1 | **DHT22 sensor module** | humidity + temp, 3-pin | ₱220 | Lazada | https://www.lazada.com.ph/products/pdp-i132179919.html |
| 1 | **DS18B20 temperature sensor module** | LEOOYI, 3-pin cable + pluggable terminal adapter | ₱141 | Lazada | https://www.lazada.com.ph/products/pdp-i4398946755-s24721782197.html |
| 1 | LCD 16×2 I2C | display | ₱165 | Lazada | https://www.lazada.com.ph/products/1602-16x2-character-lcd-module-display-hd44780-with-i2c-i104139284-s1630402476.html |
| 1 | **DC Rocker Switch 50A 12V** | Main power disconnect (heavy duty toggle) | ~₱190 | Lazada | https://www.lazada.com.ph/catalog/?q=50A+12V+DC+heavy+duty+toggle+switch |
| 3 | **PETIYOUZA Rigid Flange Coupling 6mm** | 6mm bore — shaft end → umbrella hub | ~₱107 ea = ~₱321 | Lazada | https://www.lazada.com.ph/products/petiyouza-coupler-hardware-power-transmission-parts-r11-rigid-flange-coupling-iron-motor-guide-shaft-diy-metal-coupling-i401878563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 |
| 3 | Rigid shaft coupling 6×8mm | motor output shaft → shaft | ₱82.84 ea (pack of 3) = ₱249 | Lazada | https://www.lazada.com.ph/products/pdp-i245055558.html |
| 3 | 304 SS shaft 6mm × 300mm | shaft — passes through the UCP06 pillow block middle | ~₱180 ea = ~₱540 | Lazada | https://www.lazada.com.ph/catalog/?q=304+stainless+steel+rod+6mm+300mm |
| 3 | **UCP06 pillow block bearing (6mm bore)** | holds the shaft mid-span, absorbs radial load | ₱87 ea = ₱522 | Lazada | https://www.lazada.com.ph/catalog/?q=ucp06+pillow+block+bearing+6mm |
| 1 | LED 5mm (R/Y/G) | status | ₱29 | Lazada (Makerlab PH) | https://www.lazada.com.ph/products/5mm-led-diode-assorted-colors-i144137387-s166391718.html |
| 1 | Active buzzer 5V | alarm | ₱35 | Lazada (Makerlab PH) | https://www.lazada.com.ph/products/active-alarm-buzzer-driver-module-high-current-blue-i3474748260-s17874906532.html |
| 1 | Arcade LED push button 5V | start | ₱45 | Circuitrocks | https://www.lazada.com.ph/products/i343850766.html |
| 1 | Silicone wire kit 6–18AWG | gauges | ₱218 | Lazada | https://www.lazada.com.ph/products/pdp-i4880482146.html |
| 2 | **Model 1007 Tinned Copper Wire Kit** (COLOR 01 + COLOR 02) | 18/20/22/24 AWG, 5-color spool — logic + signal wiring | ₱385 ea = ₱770 | Lazada (Makerlab PH) | https://www.lazada.com.ph/products/model-1007-18awg-20awg-22-awg-24awg-tinned-copper-wire-5-color-spool-i3154761672-s17328234744.html |
| 1 | **Terminal block 15A barrier 6-pole** | 5V rail distribution (buck out → Mega/DHT22/DS18B20/LCD/button) | ~₱132 | Lazada | https://www.lazada.com.ph/products/terminal-block-15a-25a-45a-60a-80a-100a-600v-barrier-3-poles-to-12-poles-vat-included-prices-i2818578034.html |
| 2 | 10-Terminal Bus Bar 150A (Copper) | Main 12V (+ & -) bus rails | ~₱120 ea = ₱240 | Lazada | https://www.lazada.com.ph/products/814-terminal-bus-bar-150a-high-current-dc-busbar-12-48v-copper-power-distribution-terminal-block-for-car-boat-i5119401028-s3021619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 |
| 1 | Heat-shrink tube kit | insulation | ₱111 | Lazada | https://www.lazada.com.ph/products/pdp-i2569065087.html |
| 1 | **1/4W 1% Metal Film Resistor Kit** 600pcs | 47Ω/220Ω/1K/10K/47K/68K/100K/220K/1M (20ea each) | ₱220 | Lazada (Makerlab PH) | https://www.lazada.com.ph/products/14w-resistance-1-metal-film-resistor-assorted-kit-each-20-total-600pcs-47-ohms-220-1k-10k-47k-68k-100k-220k-1m-i118492390-s1229303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 |
| 1 | **Nylon Standoff Kit M3/M2.5** | M3x6+6mm×30 + M3x10+6mm×20 + M2.5x6+6mm×20 — covers Mega, LCD, SSR mounts | ₱97 | Lazada | https://www.lazada.com.ph/products/pdp-i2946710217.html |
| 1 | Aluminum plate 6061 6mm | motor plate + mounts | ₱760 | Lazada | https://www.lazada.com.ph/products/pdp-i4449859085.html |
| 1 | LiFePO4 12.8V 200Ah w/ BMS 200A | battery | ~₱8,900 | Lazada (PowMr) | https://h5.lazada.com.ph/products/powmr-12v-200ah-lifepo4-battery-lithium-battery-built-in-bms-6000-deep-cycles-rechargeable-solar-battery-i5047514166.html |
| 1 | **VariCore 14.6V 20A Smart LiFePO4 Charger** | Alligator clip variant; CC/CV; LED red/green; 110-240V input | ~₱2,809 | Lazada | https://www.lazada.com.ph/products/varicore-146v-20a-smart-lifepo4-battery-charger-110-220v-4s-12v-high-power-charger-for-lithium-iron-phosphate-i5375251271-s3216768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 |
| 1 | **Zip ties 100pcs nylon UV-resistant** | Heavy duty, 3-tooth buckle — wire bundling | ~₱84 | Lazada | https://www.lazada.com.ph/products/100pcs-heavy-duty-nylon-cable-zip-ties-uv-resistant-multipurpose-i4164586303.html |
| 1 | **Screws M3/M4/M5 stainless 320pcs kit** | M3 8/12/16mm + M4 + washers/nuts — Mega, plate, chamber mounts | ~₱298 | Lazada | https://www.lazada.com.ph/products/320pcs-380pcs-stainless-steel-screws-bolts-nuts-kit-m3-m4-m5-hex-socket-fasteners-assortment-set-anti-loosening-washers-gaskets-di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 |
| 1 | **PROSEAL silicone sealant (clear)** | 100% RTV, waterproof, weather-resistant — seam sealing | ~₱199 | Lazada | https://www.lazada.com.ph/products/proseal-silicone-sealant-clear-white-black-brown-i4013402307.html |
| 1 | **Rubber grommets 180pcs (8 sizes)** | Wire passthrough / chamber wall penetrations | ~₱249 | Lazada | https://www.lazada.com.ph/products/same-day-shipping-180pcs-rubber-grommet-assortment-contain-8-popular-sizes-gasket-firewall-hole-plug-set-electrical-wire-gasket-ki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 |
| 1 | Zip ties, screws, sealant, grommets | consumables — hardware-store bulk alternative to the 4 online items above | ~₱490 | hardware | — |

---

## 10. Cost summary

| Category | Estimate |
|---|---|
| PTC heaters (9×₱1,162) | ≈ ₱10,460 |
| AVC blowers (9×₱330) | ≈ ₱2,970 |
| Motors + drivetrain + mounts (3× SGM-370, couplings 6×8mm, 3× shafts, 3× UCP06 pillow blocks, 3× PETIYOUZA flange, 6mm aluminum plate) | ≈ ₱3,892 |
| taxnele SSR 40A (4×₱239) + SSR 10A (4×₱218) + SSR Heatsink BLACK (4×₱110) | ≈ ₱2,270 |
| Control electronics (Mega w/ terminal board ₱413, DHT22 ₱220, DS18B20 ₱141, LCD ₱165, LM2596S ₱155, resistor kit ₱220) | ≈ ₱1,314 |
| Lid safety interlock (reed switch ₱165 + solenoid lock ₱310 + 1N4007) | ≈ ₱480 |
| Battery (1× 200Ah) + charger | ≈ ₱11,700–12,200 |
| UI (LEDs, buzzer, button) | ≈ ₱109 |
| Wiring, connectors, consumables | ≈ ₱2,400 |
| DC Rocker Switch 50A | ~₱190 |
| **TOTAL** | **≈ ₱35,800** (₱35,600–36,300 with price swings; PTC heaters now ₱1,162 ea — original ₱484 MXKJING listing out of stock; includes lid safety interlock: reed switch + solenoid lock + 4th SSR-10A) |

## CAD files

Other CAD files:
model/DCWormGearMotor.f3z
model/SSRHeatsink.f3z
model/UMBRELLADRYERV2.f3z

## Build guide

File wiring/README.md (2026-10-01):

# Wiring Reference — Arduino Mega 2560

> **CirKit Designer schematic:** https://app.cirkitdesigner.com/project/2e875907-8296-419f-81b1-bf9ca0faf2a8

> Pin map for every component. Pure 12V DC architecture: **all loads run from the battery** — no mains voltage, no inverter, no changeover switch. If any other doc disagrees with this file, this file wins.

## 0. Domains overview

| Domain | Source | Loads | Switched by |
|---|---|---|---|
| 12V DC | 1× LiFePO4 200Ah | PTC heaters, AVC blowers, worm motors, solenoid lock | 4× SSR-40DD (3 PTC + 1 fan bus, direct-drive), 4× SSR-10A (3 motors + 1 solenoid lock), PWM (D10/D11/D12) |
| 5V DC | LM2596S buck (12V→5V) | Mega, sensors, LCD | — |

> **SSR architecture:** a station's 3 PTC heaters draw ~25A — over the 10A rating
> of PCB relay modules. Every PTC group therefore uses a **DC-output SSR-40DD** (40A).
> The motor SSRs are LCTC DC-DC SSR-10A (active-HIGH). No optocoupler module needed. Each motor draws only ~0.8A.
> The fan bus (9 blowers, ~40.5A) uses SSR-40DD. A 4th SSR-10A switches the lid **solenoid lock** (~0.65A).

## 1. Pin map — Mega 2560 side

| Mega pin | Direction | Connects to | Active level | Wire / notes |
|---|---|---|---|---|
| 5V | power in | LM2596S buck OUT+ (set 5.00 V) | — | 20 AWG — never the barrel jack |
| GND | common | Ground rail (DC side) | — | 20 AWG |
| D2 | in | DHT22 DATA | — | 22 AWG + 10 kΩ pull-up to 5V |
| D3 | in | DS18B20 yellow/white DATA | — | 22 AWG + 4.7 kΩ pull-up to 5V |
| **D4** | out | Station 1 PTC SSR-40DD (input +) | HIGH = ON | 22 AWG — heater group 1 (3× 100W) |
| **D5** | out | Station 1 motor SSR-10A (input +) | HIGH = ON | 22 AWG — SGM-370 #1 |
| **D6** | out | Station 2 PTC SSR-40DD (input +) | HIGH = ON | 22 AWG — heater group 2 |
| **D7** | out | Station 2 motor SSR-10A (input +) | HIGH = ON | 22 AWG — SGM-370 #2 |
| **D8** | out | Station 3 PTC SSR-40DD (input +) | HIGH = ON | 22 AWG — heater group 3 |
| **D9** | out | Station 3 motor SSR-10A (input +) | HIGH = ON | 22 AWG — SGM-370 #3 |
| **D13** | out | Fan bus SSR-40DD (input +) | HIGH = ON | 22 AWG — powers all 9 blowers |
| **D10** | out (PWM) | Blower PWM — Station 1 | — | `analogWrite(D10, val)` 0–255 |
| **D11** | out (PWM) | Blower PWM — Station 2 | — | `analogWrite(D11, val)` 0–255 |
| **D12** | out (PWM) | Blower PWM — Station 3 | — | `analogWrite(D12, val)` 0–255 |
| **D14** | in | Start button (other side → GND) | LOW = pressed | INPUT_PULLUP |
| D15 | out | Red LED (heater active) via 220 Ω | HIGH = ON | 22 AWG |
| D16 | out | Yellow LED (cycle running) via 220 Ω | HIGH = ON | 22 AWG |
| D17 | out | Green LED (done) via 220 Ω | HIGH = ON | 22 AWG |
| D18 | out | Active buzzer + (− → GND) | HIGH = ON | 22 AWG |
| **D22** | in | **Lid reed switch** (other side → GND) | **LOW = lid CLOSED** | INPUT_PULLUP |
| **D23** | out | **Solenoid lock SSR-10A (input +)** | **HIGH = UNLOCK (pulse ~3 s)** | 22 AWG |
| **20 (SDA)** | I2C | LCD SDA | — | addr 0x27 or 0x3F |
| **21 (SCL)** | I2C | LCD SCL | — | Mega I2C is pins 20/21 — NOT A4/A5 |

> Mixed active levels are deliberate: SSRs are active-HIGH by design — a floating pin at boot = SSR OFF (boot-safe).
> The lid safety interlock uses D22 (reed input) and D23 (solenoid SSR). The solenoid lock is **normally-locked
> (fail-secure)**: an ON pulse to D23 retracts the bolt (unlocks); spring re-locks on its own the rest of the time.

## 2. 12V DC power distribution

The system uses **two heavy-duty 10-terminal 150A copper bus bars** (20 holes total) for the main high-current 12V DC power distribution (Positive and Negative/GND). The existing **15A Barrier Terminal Block** remains unchanged; do not replace or rewire it for this bus-bar change.

| From | To | Wire | Protection |
|---|---|---|---|
| Battery + | 2-pin screw terminal (battery in) | 8 AWG | — |
| Battery − | 12V Negative Ground Bus Bar (10-Terminal Copper) | 8 AWG | — |
| Screw terminal + | 12V Positive Bus Bar (10-Terminal Copper) | 8 AWG | — |
| 12V Positive Bus | Station 1 PTC branch → SSR-40DD → heaters | 10 AWG | — |
| 12V Positive Bus | Station 2 PTC branch → SSR-40DD → heaters | 10 AWG | — |
| 12V Positive Bus | Station 3 PTC branch → SSR-40DD → heaters | 10 AWG | — |
| 12V Positive Bus | Fan bus branch → SSR-40DD → blower distribution | 10 AWG | — |
| 12V Positive Bus | Motor 1/2/3 branches → SSR-10A COM/NO → motors | 18 AWG | — |
| 12V Positive Bus | **Solenoid lock branch → SSR-10A (D23) → solenoid lock** | **20 AWG** | — |
| 12V Positive Bus | Buck IN+ (logic power) | 20 AWG | — |
| All returns | 12V Negative Ground Bus Bar (10-Terminal Copper) → bank − | — | chassis bonded at one bolt |
| Buck OUT+ (5V) | Mega 5V pin, sensors, LCD, button LED ring | 20 AWG | set 5.00 V first |

> **Staged operation is mandatory:** one station's PTC + fans + motor ≈ 36A. Two
> stations at once ≈ 70A — exceeds the BMS 200A continuous rating and stresses the
> battery. The firmware enforces one station at a time (`docs/FIRMWARE-GUIDE.md`).
> With fuses removed, the BMS + firmware cutoff are the only over-current protections.
> The solenoid lock draws ~0.65A **only during brief unlock pulses** (~3 s); it draws 0 A
> while locked, so it adds no meaningful draw to the running budget.

## 3. Station PTC branch — SSR-40DD (×3, D4/D6/D8)

Each station's 3 PTC heaters (~25A) are switched by one DC-output SSR-40DD (40A, input 3–32VDC).

| SSR terminal | Goes to |
|---|---|
| IN+ | Mega pin D4/D6/D8 |
| IN− | GND |
| COM (input side) | +12V bus |
| NO (output side) | Parallel + leads of the 3 PTC heaters |

> Pin HIGH → SSR energizes (≈10–20 mA input current). Pin floats/LOW at boot → SSR OFF.

**Heater side:** PTC − leads → ground rail. Each SSR requires a heatsink (dissipation ≈1 W/A → ~25 W per PTC SSR at 25A).

## 4. Motor branch — LCTC DC-DC SSR 10A (D5/D7/D9)

| SSR terminal | Goes to |
|---|---|
| IN+ | Mega pin D5/D7/D9 |
| IN− | GND |
| COM (input side) | +12V motor branch |
| NO (output side) | SGM-370 motor + |

Active-HIGH: `digitalWrite(pin, HIGH)` = SSR ON. Floating pin at boot = SSR OFF (no input current).

## 5. Fan power bus — LCTC DC-DC SSR 40A (D13)

| SSR terminal | Goes to |
|---|---|
| IN+ | Mega pin D13 |
| IN− | GND |
| COM (input side) | +12V bus |
| NO (output side) | Blower distribution block — VIN of all 9 blowers in parallel |

D13 HIGH → all blowers powered. D13 LOW → every blower dies instantly (emergency kill).
On the Mega, D13 also blinks the onboard LED when the fan bus is on — free indicator.

## 5b. Lid safety interlock — reed switch + solenoid lock (D22 / D23)

The chamber front lid has an automatic bolt lock (fail-secure solenoid) and a closed-lid
detector. **The machine will not start a drying cycle unless the lid is closed**, and the
lid is **locked shut for the whole cycle** — both are for safety (no access to rotating
umbrellas or heated air while running).

| Item | Part | Pins | Notes |
|---|---|---|---|
| Lid-closed sensor | **Magnetic Door Reed Switch Set NO/NC** (Makerlab PH) | D22 + GND | NO mode: lid closed (magnet near) = contacts close = D22 LOW. INPUT_PULLUP on D22. OPEN = HIGH |
| Lid lock | **Solenoid Lock 12VDC** (Makerlab PH), switched by the 4th **SSR-10A** | D23 (SSR input) | Normally-locked bolt; ON pulse retracts (unlocks). ~650 mA @ 12 V, 1–10 s duty — pulse only |

**Reed switch wiring (door-closed detection):**

| Terminal | Goes to |
|---|---|
| Reed lead 1 | Mega **D22** (INPUT_PULLUP enabled; pull-up holds HIGH when open) |
| Reed lead 2 | GND |
| Magnet (mount on the door) | Align with the reed housing on the frame so the pair closes when the lid is fully shut |

NO/NC configurable set: use the **NO** contacts (closed when the magnet is near). Closed lid → read `LOW`.

**Solenoid lock wiring (via the 4th SSR-10A):**

| SSR terminal | Goes to |
|---|---|
| IN+ | Mega pin **D23** |
| IN− | GND |
| COM (input side) | +12V bus |
| NO (output side) | Solenoid lock + lead |
| Solenoid − lead | GND |
| 1N4007 flyback diode | Across the solenoid terminals (cathode/banded → solenoid **+**) — protects the SSR output MOSFET from inductive kickback |

Active-HIGH: `digitalWrite(D23, HIGH)` energizes the solenoid → bolt retracts → **UNLOCK**.
`digitalWrite(D23, LOW)` → bolt returns (spring) → **LOCKED**. Keep the ON pulse ~3 s (the solenoid is rated for 1–10 s activation, not continuous hold).

> **Fail-secure by design:** the bolt is spring-locked whenever D23 is LOW (or power is lost).
> During a drying cycle D23 stays LOW, so the lid is mechanically locked with **0 A draw**.
> On power loss mid-cycle the lid stays locked until power is restored and the solenoid is pulsed
> open — an intentional safety trade-off (running heater/fan/motor loads also drop instantly on 12 V loss).

## 6. Blower PWM wiring (D10/D11/D12)

Each of the 9 AVC blowers accepts PWM duty cycle directly from Mega pins via `analogWrite()`. Per station, the 3 blowers share one Mega PWM pin.

| Blower wire | Goes to |
|---|---|
| VIN (red) | Fan bus from SSR-40DD (10 AWG bus → 18 AWG pigtails) |
| GND (black) | Common ground rail |
| PWM signal | D10 (station 1) / D11 (station 2) / D12 (station 3) — 3 leads per pin |

> **No ESC needed.** `analogWrite(D, 255)` = full speed. `analogWrite(D, 0)` = off.

## 7. Sensor wiring

| Sensor | Wire | Goes to |
|---|---|---|
| DHT22 | VCC / GND / DATA | 5V rail / ground rail / D2 + 10 kΩ pull-up to 5V |
| DS18B20 | red / black / yellow(white) | 5V rail / ground rail / D3 + 4.7 kΩ pull-up to 5V |
| LCD 16×2 I2C | VCC / GND / SDA / SCL | 5V rail / ground rail / **D20** / **D21** |

## 8. UI wiring

| Part | Goes to |
|---|---|
| Arcade button | pin 1 → D14, pin 2 → GND (INPUT_PULLUP). LED ring: + → 5V, − → GND |
| Red LED | anode → D15 via 220 Ω, cathode → GND |
| Yellow LED | anode → D16 via 220 Ω, cathode → GND |
| Green LED | anode → D17 via 220 Ω, cathode → GND |
| Active buzzer | + → D18, − → GND |

## 9. Wire gauge schedule

| Run | Gauge |
|---|---|
| Battery → screw terminal → bus | 8 AWG |
| Bus → station PTC SSR → heaters | 10 AWG |
| Bus → fan SSR → blower distribution | 10 AWG (18 AWG signal pigtails) |
| Bus → motor branch → module → motor | 18 AWG |
| **Bus → solenoid lock SSR → solenoid** | **20 AWG** |
| Bus → buck IN+ | 20 AWG |
| Buck OUT → 5V rail | 20 AWG |
| All Mega signal / sensor jumpers | 22 AWG |

## 10. Safety features

1. **PTC self-regulation** — current drops as element temperature rises
2. **DS18B20 firmware cutoff** at 65 °C — cuts PTC SSRs + motor SSRs + fan bus
3. **Boot-safe by design** — All SSRs are active-HIGH (floating pin at boot = SSR OFF). PWM pins default LOW = blowers off. `allOff()` called first in `setup()`. The solenoid SSR is LOW at boot = lid locked (fail-secure).
4. **No mains voltage** — entire system is SELV
5. **Single-point DC ground** — all returns meet at one bus bar
6. **Emergency kill** — pull battery cable from 2-pin screw terminal OR flip 50A rocker switch OFF
7. **BMS 200A** — over-current protection on battery output
8. **Lid safety interlock** — the machine will not start a drying cycle while the lid is open (reed switch D22 gates the start button); the lid is locked shut (solenoid D23) for the whole cycle and only unlocked at COMPLETE (and on demand for loading)

> With fuses removed, the BMS and firmware cutoff are the only over-current/over-temperature
> protections. There is no hardware fuse backstop anymore.

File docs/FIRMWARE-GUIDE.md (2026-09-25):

# Firmware Guide — 12V DC + AVC Blower Fans

> Complete firmware reference for the Umbrella Dryer V2 running on a **12V DC-only** system. AVC blowers are controlled via direct PWM from Mega pins (D10/D11/D12). PTC heaters and worm motors are switched by SSRs (SSR-40DD for PTC, SSR-10A for motors). No ESCs, no Servo library. DRY phase ends early when chamber humidity bottoms out (≤ 60% RH) — the energy-efficient control of the study.

---

## 1. System Logic and State Machine

### 1a. Operational Sequence

1. **Boot** → Initialized. All SSR outputs LOW (OFF). Fan bus SSR (D13) is OFF. Lid solenoid SSR (D23) LOW = **lid locked (fail-secure)**. Blowers remain off until cycle starts.
2. **Idle** → Reads DHT22 (humidity) + DS18B20 (temperature), displays on LCD. Button waits for input. Status LED is **GREEN**. The LCD shows the lid state; **hold Start ~2 s to UNLOCK the lid for loading** (bolt retracts ~3 s, then re-locks).
3. **Button tap (release < 2 s)** → Starts a 4-phase drying cycle **only if the lid is CLOSED** (reed switch D22 reads LOW). If the lid is open, the start is **refused** (buzzer + "CLOSE LID") — the machine will not run with the lid open. Once started, the lid is spring-***LOCKED*** for the whole cycle (solenoid off, 0 A).
   - **Phase 1 — Preheat** (Chamber Temp < 45°C): Master fan bus SSR (D13) ON. Blowers throttle to FULL (`analogWrite(D, 255)`). PTC heater SSRs D4, D6, D8 are energized (ON) sequentially to warm up the chamber. Motors remain OFF. Status LED is **RED** (heating active).
   - **Phase 2 — Dry** (Chamber Temp ≥ 45°C): Chamber temperature has reached target. Station worm gear motor SSRs D5, D7, D9 are switched ON to spin the umbrellas at 6 RPM. PTC heaters and blowers continue running. Timer starts counting down (default 15 minutes). **Humidity auto-stop:** if DHT22 reads ≤ 60% RH after at least 3 minutes of drying, the cycle skips straight to COOL — no wasted energy on already-dry umbrellas. Status LED is **YELLOW** (drying/spinning).
   - **Phase 3 — Cool** (Timer Done): PTC heaters switched OFF. Motors switched OFF (umbrellas stop spinning). Blowers remain running at full speed for 2 minutes to purge hot air and cool down the components. Status LED is **YELLOW**.
   - **Phase 4 — Done**: All loads de-energized. Master fan bus SSR OFF. Buzzer beeps 3 times. LCD shows "COMPLETE". Status LED is **GREEN**. The **lid is pulsed UNLOCKED (~3 s)** so the user can retrieve the umbrellas ("Lid UNLOCKED - open"). After closing, a tap resets to IDLE.
4. **Safety cutoff (any active phase)**: If DS18B20 reads >65°C, all SSRs and PWM signals are immediately killed (latched OFF). LCD displays "THERMAL CUTOFF!" and the RED LED blinks.
5. **Button tap (any active phase)**: Functions as an Emergency Stop. Immediately cuts all loads and returns the system to IDLE. (The lid remains locked until you hold Start ~2 s to unlock it.)
6. **Lid-open safety interlock (any active phase)**: If the reed switch reads OPEN mid-cycle — impossible while the lock holds — the firmware aborts everything to IDLE (defense in depth against a failed lock).

---

## 2. Pin Map — Arduino Mega 2560

| | Pin | Net | Mode | Default | Active Level | Notes |
|---|---|---|---|---|---|---|
| | **D2** | DHT22_DATA | Input | — | — | Chamber humidity & ambient temp; 10kΩ pull-up to 5V |
| | **D3** | DS18B20_DATA | Input | — | — | Heater-zone temperature probe; 4.7kΩ pull-up to 5V |
| | **D4** | SSR_PTC_1 | Output | LOW | HIGH (ON) | Station 1 PTC heater (LCTC DC-DC SSR 40A) |
| | **D5** | SSR_MOTOR_1 | Output | LOW | HIGH (ON) | Station 1 worm motor (LCTC DC-DC SSR 10A) |
| | **D6** | SSR_PTC_2 | Output | LOW | HIGH (ON) | Station 2 PTC heater (LCTC DC-DC SSR 40A) |
| | **D7** | SSR_MOTOR_2 | Output | LOW | HIGH (ON) | Station 2 worm motor (LCTC DC-DC SSR 10A) |
| | **D8** | SSR_PTC_3 | Output | LOW | HIGH (ON) | Station 3 PTC heater (LCTC DC-DC SSR 40A) |
| | **D9** | SSR_MOTOR_3 | Output | LOW | HIGH (ON) | Station 3 worm motor (LCTC DC-DC SSR 10A) |
| | **D10** | PWM_FAN_1 | Output (PWM) | 0 | — | Station 1 blower PWM (`analogWrite`) |
| | **D11** | PWM_FAN_2 | Output (PWM) | 0 | — | Station 2 blower PWM (`analogWrite`) |
| | **D12** | PWM_FAN_3 | Output (PWM) | 0 | — | Station 3 blower PWM (`analogWrite`) |
| | **D13** | SSR_FAN_BUS | Output | LOW | HIGH (ON) | Master Fan Bus (LCTC DC-DC SSR 40A) |
| | **D14** | BTN_START | Input | HIGH | LOW (ON) | Arcade start button (internal pull-up enabled) |
| | **D15** | LED_RED | Output | LOW | HIGH (ON) | Status LED: active heating |
| | **D16** | LED_YELLOW | Output | LOW | HIGH (ON) | Status LED: drying and rotating / cooling |
| | **D17** | LED_GREEN | Output | HIGH | HIGH (ON) | Status LED: system ready or cycle complete |
| | **D18** | BUZZER | Output | LOW | HIGH (ON) | Active 5V buzzer |
| | **D22** | LID_REED | Input | HIGH | LOW (CLOSED) | Lid closed sensor (NO reed, INPUT_PULLUP) |
| | **D23** | SOL_LOCK | Output | LOW | HIGH (UNLOCK) | Lid solenoid lock (SSR-10A) — pulse ~3 s |
| | **D20** | I2C_SDA | I2C | — | — | LCD SDA pin (hardware I2C) |
| | **D21** | I2C_SCL | I2C | — | — | LCD SCL pin (hardware I2C) |

> All SSRs are active-HIGH. Floating pins at boot default LOW = SSR OFF. `allOff()` in `setup()` enforces safe state.
> **Lid interlock:** D23 (SOL_LOCK) LOW = lid LOCKED (fail-secure, 0 A). A ~3 s HIGH pulse on D23 retracts the bolt (UNLOCK) — used at cycle COMPLETE and when holding Start ~2 s in IDLE to load. The START button only begins a cycle while D22 (LID_REED) reads LOW (lid closed).

---

## 3. Timing and Control Thresholds

| Parameter | Value | Design Rationale / Notes |
|---|---|---|
| **Loop Tick Interval** | 500 ms | Prevents sensor bus congestion; provides stable sensor readings |
| **Preheat Threshold** | 45.0°C | Chamber air temp target required to enable safe centrifugal drying |
| **Thermal Cutoff** | 65.0°C | Absolute maximum chamber ceiling; triggers immediate system lock |
| **Dry Phase Timer** | 15 minutes (max) | Standard cycle ceiling; sufficient for complete moisture removal |
| **Humidity Auto-Stop** | ≤ 60% RH, after ≥ 3 min drying | Chamber RH bottoms out once umbrellas are dry — cycle skips to COOL; saves the unused portion of the 15-minute budget |
| **Min Dry Time before Auto-Stop** | 3 minutes | Guards against stale/spike DHT22 readings ending the cycle early |
| **Cool Phase Timer** | 2 minutes | Blower-only overrun to dissipate residual heater block temperature |
| **Debounce Delay** | 300 ms | Ignores button contact bounce and microphonics |
| **Lid Hold-to-Unlock** | 2 seconds | Hold Start in IDLE to retract the lock bolt for loading |
| **Lid Unlock Pulse** | 3 seconds | Length of the D23 SSR pulse that retracts the bolt (solenoid is rated for 1–10 s activation — never hold it on) |

---

## 4. Complete Arduino Sketch

Copy and paste the following complete, verified sketch into the Arduino IDE.

```cpp
// ============================================================================
// Umbrella Dryer V2 — 12V DC-Only System Firmware
// Target Board: Arduino Mega 2560
// Dependencies: DHT, OneWire, DallasTemperature, LiquidCrystal_I2C
// ============================================================================

#include <DHT.h>
#include <OneWire.h>
#include <DallasTemperature.h>
#include <LiquidCrystal_I2C.h>

// ---- Pin Definitions ----
#define PIN_DHT22         2
#define PIN_DS18B20       3

// Actuators
#define PIN_SSR_PTC_1   4   // LCTC DC-DC SSR 40A (Station 1 Heaters)
#define PIN_SSR_MOTOR_1 5   // LCTC DC-DC SSR 10A (Station 1 Motor)
#define PIN_SSR_PTC_2   6   // LCTC DC-DC SSR 40A (Station 2 Heaters)
#define PIN_SSR_MOTOR_2 7   // LCTC DC-DC SSR 10A (Station 2 Motor)
#define PIN_SSR_PTC_3   8   // LCTC DC-DC SSR 40A (Station 3 Heaters)
#define PIN_SSR_MOTOR_3 9   // LCTC DC-DC SSR 10A (Station 3 Motor)

#define PIN_PWM_FAN_1     10  // Station 1 AVC blower PWM
#define PIN_PWM_FAN_2     11  // Station 2 AVC blower PWM
#define PIN_PWM_FAN_3     12  // Station 3 AVC blower PWM
#define PIN_SSR_FAN_BUS   13  // LCTC DC-DC SSR 40A (Master Fan Bus)

// UI and Peripherals
#define PIN_BTN_START     14  // Arcade button (active-LOW, pull-up)
#define PIN_LED_RED       15  // Active heating
#define PIN_LED_YELLOW    16  // Centrifugal drying / Cooling
#define PIN_LED_GREEN     17  // System ready / Cycle complete
#define PIN_BUZZER        18  // Audible notifications

// ---- Lid Safety Interlock ----
#define PIN_REED          22  // Lid closed sensor (NO reed, INPUT_PULLUP; LOW = LID CLOSED)
#define PIN_SOL_LOCK      23  // Solenoid lock SSR-10A (HIGH = UNLOCK pulse; LOW = LOCKED)

// ---- Sensor Objects ----
DHT dht(PIN_DHT22, DHT22);
OneWire oneWire(PIN_DS18B20);
DallasTemperature ds18b20(&oneWire);
LiquidCrystal_I2C lcd(0x27, 16, 2);  // Alternate address: 0x3F

// ---- Configuration and Constants ----
const float PREHEAT_TEMP   = 45.0;                      // °C - dry trigger
const float CUTOFF_TEMP    = 65.0;                      // °C - safety threshold
const float HUMIDITY_STOP  = 60.0;                      // % RH - early stop: chamber is dry
const unsigned long MIN_DRY_TIME_MS = 3UL * 60UL * 1000UL; // min drying before auto-stop is allowed
const unsigned long DRY_TIME_MS  = 15UL * 60UL * 1000UL; // 15-minute drying timer (max)
const unsigned long COOL_TIME_MS = 2UL * 60UL * 1000UL;  // 2-minute cooling run
const int PWM_FULL         = 255;                       // Full blower speed
const int PWM_OFF          = 0;                         // Blower off

// ---- Staged operation (one station at a time — keeps draw ~39A under BMS 200A) ----
const uint8_t PIN_PTC[3]   = { PIN_SSR_PTC_1,  PIN_SSR_PTC_2,  PIN_SSR_PTC_3  };
const uint8_t PIN_MOT[3]   = { PIN_SSR_MOTOR_1, PIN_SSR_MOTOR_2, PIN_SSR_MOTOR_3 };
const uint8_t PIN_PWM[3]   = { PIN_PWM_FAN_1,  PIN_PWM_FAN_2,  PIN_PWM_FAN_3  };
const unsigned long STAGE_MS = 30000;   // 30 s per station before rotating
uint8_t activeStation = 0;
unsigned long stageStart = 0;

// Energize ONLY the active station: PTC always, motor only in DRY, PWM fans always
void applyStage(bool dryMotors) {
  for (uint8_t i = 0; i < 3; i++) {
    digitalWrite(PIN_PTC[i], LOW);
    digitalWrite(PIN_MOT[i], LOW);
    analogWrite(PIN_PWM[i], PWM_OFF);
  }
  digitalWrite(PIN_PTC[activeStation], HIGH);
  analogWrite(PIN_PWM[activeStation], PWM_FULL);
  if (dryMotors) digitalWrite(PIN_MOT[activeStation], HIGH);
}

// Rotate to the next station every STAGE_MS
void rotateStage(unsigned long now) {
  if (now - stageStart >= STAGE_MS) {
    stageStart = now;
    activeStation = (activeStation + 1) % 3;
    Serial.print("Stage rotate -> station ");
    Serial.println(activeStation + 1);
  }
}

// ---- System State Machine ----
enum State { STATE_IDLE, STATE_PREHEAT, STATE_DRY, STATE_COOL, STATE_DONE, STATE_CUTOFF };
State currentPhase = STATE_IDLE;

unsigned long phaseStart  = 0;
unsigned long lastLoopTick = 0;
float humidity            = 0;
float temperature         = 0;
bool buttonPrevState      = HIGH;
unsigned long btnDownAt   = 0;    // timestamp when Start was pressed (for tap-vs-hold)
bool btnWasDown           = false; // Start currently held
bool btnUnlockSent        = false; // prevent repeat unlocks during one long hold

// ---- Lid Lock Helpers (fail-secure solenoid) ----
// The solenoid is NORMALLY-LOCKED: the bolt stays out (LID LOCKED) with zero power.
// A HIGH pulse retracts the bolt (UNLOCK) for ~3 s. Rated 1-10 s only — never hold it on.
void unlockLid() {
  digitalWrite(PIN_SOL_LOCK, HIGH);
  delay(3000);                 // hold bolt retracted ~3 s so the user can pull the lid open
  digitalWrite(PIN_SOL_LOCK, LOW);
  Serial.println(F("Lid UNLOCKED (bolt retracted 3 s)"));
}

inline bool lidIsClosed() {
  return digitalRead(PIN_REED) == LOW;   // magnet near reed (lid shut) = reed shorted = LOW
}

// ---- Absolute System Safety Shutdown ----
void allOff() {
  digitalWrite(PIN_SSR_PTC_1, LOW);
  digitalWrite(PIN_SSR_PTC_2, LOW);
  digitalWrite(PIN_SSR_PTC_3, LOW);
  digitalWrite(PIN_SSR_MOTOR_1, LOW);
  digitalWrite(PIN_SSR_MOTOR_2, LOW);
  digitalWrite(PIN_SSR_MOTOR_3, LOW);
  analogWrite(PIN_PWM_FAN_1, PWM_OFF);
  analogWrite(PIN_PWM_FAN_2, PWM_OFF);
  analogWrite(PIN_PWM_FAN_3, PWM_OFF);
  digitalWrite(PIN_SSR_FAN_BUS, LOW);
  digitalWrite(PIN_LED_RED, LOW);
  digitalWrite(PIN_LED_YELLOW, LOW);
  digitalWrite(PIN_LED_GREEN, LOW);
  digitalWrite(PIN_BUZZER, LOW);
  digitalWrite(PIN_SOL_LOCK, LOW);   // lid LOCKED (fail-secure) — never energized during a cycle
}

// ---- Fan Control ----
void fansOn() {
  digitalWrite(PIN_SSR_FAN_BUS, HIGH);
  delay(100);
  analogWrite(PIN_PWM_FAN_1, PWM_FULL);
  analogWrite(PIN_PWM_FAN_2, PWM_FULL);
  analogWrite(PIN_PWM_FAN_3, PWM_FULL);
}

void fansOff() {
  analogWrite(PIN_PWM_FAN_1, PWM_OFF);
  analogWrite(PIN_PWM_FAN_2, PWM_OFF);
  analogWrite(PIN_PWM_FAN_3, PWM_OFF);
  delay(50);
  digitalWrite(PIN_SSR_FAN_BUS, LOW);
}

// ---- Sensor Data Acquisition ----
void readSensors() {
  humidity = dht.readHumidity();
  ds18b20.requestTemperatures();
  float tempRead = ds18b20.getTempCByIndex(0);
  
  if (tempRead != DEVICE_DISCONNECTED_C) {
    temperature = tempRead;
  }
}

// ---- Display Management ----
void lcdUpdate(const char* stateName, int rMin, int rSec) {
  lcd.setCursor(0, 0);
  lcd.print("H:");
  if (isnan(humidity)) {
    lcd.print("ERR");
  } else {
    lcd.print((int)humidity);
    lcd.print("%");
  }
  lcd.print(" T:");
  lcd.print((int)temperature);
  lcd.print("C    ");

  lcd.setCursor(0, 1);
  lcd.print(stateName);
  lcd.print(" ");
  if (rMin >= 0) {
    if (rMin < 10) lcd.print("0");
    lcd.print(rMin);
    lcd.print(":");
    if (rSec < 10) lcd.print("0");
    lcd.print(rSec);
  } else {
    lcd.print("     ");
  }
  lcd.print("  ");
}

// ---- System Initialization ----
void setup() {
  Serial.begin(115200);
  Serial.println("Umbrella Dryer V2 — 12V DC System Boot Initializing");

  // Actuator Output Setup & Hard Pull-Offs
  pinMode(PIN_SSR_PTC_1, OUTPUT);
  pinMode(PIN_SSR_PTC_2, OUTPUT);
  pinMode(PIN_SSR_PTC_3, OUTPUT);
  pinMode(PIN_SSR_MOTOR_1, OUTPUT);
  pinMode(PIN_SSR_MOTOR_2, OUTPUT);
  pinMode(PIN_SSR_MOTOR_3, OUTPUT);
  pinMode(PIN_PWM_FAN_1, OUTPUT);
  pinMode(PIN_PWM_FAN_2, OUTPUT);
  pinMode(PIN_PWM_FAN_3, OUTPUT);
  pinMode(PIN_SSR_FAN_BUS, OUTPUT);

  pinMode(PIN_LED_RED, OUTPUT);
  pinMode(PIN_LED_YELLOW, OUTPUT);
  pinMode(PIN_LED_GREEN, OUTPUT);
  pinMode(PIN_BUZZER, OUTPUT);
  pinMode(PIN_SOL_LOCK, OUTPUT);       // solenoid lock SSR

  // Put system in completely safe offline state
  allOff();

  // Input Setup
  pinMode(PIN_BTN_START, INPUT_PULLUP);
  pinMode(PIN_REED, INPUT_PULLUP);     // lid-closed reed sensor (LOW = lid closed)

  // Initialize Peripherals
  dht.begin();
  ds18b20.begin();
  lcd.init();
  lcd.backlight();

  lcd.setCursor(0, 0);
  lcd.print("Umbrella Dryer");
  lcd.setCursor(0, 1);
  lcd.print("V2 DC SYSTEM");
  delay(1500);

  // Settle on READY State
  digitalWrite(PIN_LED_GREEN, HIGH);
  lcd.clear();
  lcd.setCursor(0, 0);
  lcd.print("SYSTEM READY");
  lcd.setCursor(0, 1);
  lcd.print("Press Button");
}

// ---- Main Control Loop ----
void loop() {
  unsigned long now = millis();
  
  // Stable 500 ms loop interval
  if (now - lastLoopTick < 500) return;
  lastLoopTick = now;

  readSensors();

  // ---- Absolute Over-Temperature Interlock ----
  if (temperature > CUTOFF_TEMP && currentPhase != STATE_IDLE && currentPhase != STATE_CUTOFF) {
    Serial.print("CRITICAL THERMAL CUTOFF TRIP: ");
    Serial.println(temperature);
    allOff();
    currentPhase = STATE_CUTOFF;
    phaseStart = now;
    return;
  }

  // ---- Lid-open Interlock (defense in depth) ----
  // The fail-secure solenoid holds the lid locked for the whole cycle, so an OPEN reading
  // mid-cycle means the solenoid failed or the lid was forced. Kill all loads and return to IDLE.
  if (!lidIsClosed() &&
      (currentPhase == STATE_PREHEAT || currentPhase == STATE_DRY || currentPhase == STATE_COOL)) {
    Serial.println(F("LID OPENED DURING CYCLE - SAFETY ABORT"));
    allOff();
    currentPhase = STATE_IDLE;
    return;
  }

  // ---- Non-blocking Button Detection (tap vs hold) ----
  // Quick tap  = "click" (start / estop). Hold ~2 s in IDLE = "unlock lid for loading".
  // Act on the RELEASE edge so a deliberate hold doesn't accidentally start a cycle.
  bool buttonState = digitalRead(PIN_BTN_START);
  bool buttonClicked = false;                 // short tap completed
  bool longHold = false;                      // 2 s hold completed (unlock gesture)

  if (buttonState == LOW) {
    if (!btnWasDown) { btnDownAt = now; btnUnlockSent = false; btnWasDown = true; }
    if (!btnUnlockSent && (now - btnDownAt >= 2000)) { longHold = true; btnUnlockSent = true; }
  } else {
    if (btnWasDown && (now - btnDownAt < 2000)) buttonClicked = true;   // short tap released
    btnWasDown = false;
  }
  buttonPrevState = buttonState;   // diagnostics

  // ---- State Machine Logic ----
  switch (currentPhase) {

    // ================= STATE READY/IDLE =================
    case STATE_IDLE:
      digitalWrite(PIN_LED_GREEN, HIGH);
      digitalWrite(PIN_LED_RED, LOW);
      digitalWrite(PIN_LED_YELLOW, LOW);

      // Hold Start ~2 s to UNLOCK the lid for loading (bolt retracts ~3 s, then re-locks).
      if (longHold) {
        Serial.println(F("UNLOCKING LID FOR LOADING"));
        lcd.clear(); lcd.setCursor(0,0); lcd.print("UNLOCKING LID");
        lcd.setCursor(0,1); lcd.print("OPEN + LOAD");
        unlockLid();
      }

      lcdUpdate("READY", -1, -1);
      if (!lidIsClosed()) {
        lcd.setCursor(0, 1);
        lcd.print("LID OPEN  Hold unlock");
      }

      // START is safety-gated by the lid-closed reed switch: the machine will NOT start
      // with the lid open. Closing the lid and tapping Start begins the cycle.
      if (buttonClicked) {
        if (lidIsClosed()) {
          Serial.println("CYCLE COMMENCING (lid closed)");
          digitalWrite(PIN_LED_GREEN, LOW);
          digitalWrite(PIN_LED_RED, HIGH);
          currentPhase = STATE_PREHEAT;
          phaseStart = now;
          fansOn();
          activeStation = 0;
          stageStart = now;
          applyStage(false); // PTC heaters only, motors off
          // Lid stays LOCKED for the whole cycle (solenoid LOW / fail-secure).
        } else {
          Serial.println("START BLOCKED - LID OPEN");
          lcd.clear();
          lcd.setCursor(0,0); lcd.print("CLOSE LID");
          lcd.setCursor(0,1); lcd.print("To Start Cycle");
          for (int i = 0; i < 3; i++) {   // warning beeps
            digitalWrite(PIN_BUZZER, HIGH); delay(150); digitalWrite(PIN_BUZZER, LOW); delay(150);
          }
        }
      }
      break;

    // ================= STATE PREHEAT =================
    case STATE_PREHEAT:
      {
        int elapsed = (int)((now - phaseStart) / 1000);
        lcdUpdate("PREHEAT", elapsed / 60, elapsed % 60);

        applyStage(false);  // staged: rotates station every 30 s automatically
        rotateStage(now);

        if (temperature >= PREHEAT_TEMP) {
          Serial.println("CHAMBER WARMED. ENTERING CENTRIFUGAL DRYING PHASE");
          digitalWrite(PIN_LED_RED, LOW);
          digitalWrite(PIN_LED_YELLOW, HIGH);
          currentPhase = STATE_DRY;
          phaseStart = now;
          stageStart = now;
          applyStage(true); // staged PTC + motor for active station
        }
        
        if (buttonClicked) {
          Serial.println("CYCLE ABORTED DURING PREHEAT");
          allOff();
          currentPhase = STATE_IDLE;
        }
      }
      break;

    // ================= STATE CENTRIFUGAL DRYING =================
    case STATE_DRY:
      {
        unsigned long elapsed = now - phaseStart;
        unsigned long remaining = 0;
        
        if (elapsed < DRY_TIME_MS) {
          remaining = (DRY_TIME_MS - elapsed) / 1000;
        }
        
        int rMin = (int)(remaining / 60);
        int rSec = (int)(remaining % 60);
        lcdUpdate("DRYING", rMin, rSec);

        applyStage(true);   // staged: PTC + motor for active station
        rotateStage(now);

        // ---- Humidity auto-stop (energy-efficient control) ----
        // Chamber RH bottoms out once the umbrellas are dry — end early.
        // The 3-minute floor prevents a stale DHT22 reading from ending the cycle.
        if (elapsed >= MIN_DRY_TIME_MS && !isnan(humidity) && humidity <= HUMIDITY_STOP) {
          Serial.print("HUMIDITY TARGET REACHED (");
          Serial.print(humidity);
          Serial.println("% RH). ENDING DRY PHASE EARLY.");
          currentPhase = STATE_COOL;
          phaseStart = now;
          break;
        }

        if (elapsed >= DRY_TIME_MS) {
          Serial.println("TIMER ELAPSED. ENTERING COOL-DOWN");
          currentPhase = STATE_COOL;
          phaseStart = now;
        }
        
        if (buttonClicked) {
          Serial.println("CYCLE ABORTED DURING DRYING RUN");
          allOff();
          currentPhase = STATE_IDLE;
        }
      }
      break;

    // ================= STATE COOL-DOWN PURGE =================
    case STATE_COOL:
      {
        unsigned long elapsed = now - phaseStart;
        unsigned long remaining = 0;
        
        if (elapsed < COOL_TIME_MS) {
          remaining = (COOL_TIME_MS - elapsed) / 1000;
        }
        
        int rMin = (int)(remaining / 60);
        int rSec = (int)(remaining % 60);
        lcdUpdate("COOLING", rMin, rSec);

        if (elapsed >= COOL_TIME_MS) {
          Serial.println("CYCLE COMPLETE. DE-ENERGIZING FANS.");
          fansOff();
          allOff();            // all loads OFF; lid solenoid LOW (locked, fail-secure)
          currentPhase = STATE_DONE;
          phaseStart = now;
          
          // Audible cycle completion notification (3 long beeps)
          digitalWrite(PIN_LED_GREEN, HIGH);
          for (int i = 0; i < 3; i++) {
            digitalWrite(PIN_BUZZER, HIGH);
            delay(500);
            digitalWrite(PIN_BUZZER, LOW);
            delay(300);
          }
          unlockLid();         // retract bolt ~3 s so the user can retrieve the umbrellas
          lcd.clear();
          lcd.setCursor(0,0); lcd.print("COMPLETE");
          lcd.setCursor(0,1); lcd.print("Lid UNLOCKED - open");
        }
        
        if (buttonClicked) {
          Serial.println("CYCLE ABORTED DURING COOL-DOWN");
          allOff();
          currentPhase = STATE_IDLE;
        }
      }
      break;

    // ================= STATE CYCLE COMPLETE =================
    case STATE_DONE:
      digitalWrite(PIN_LED_GREEN, HIGH);
      lcdUpdate("COMPLETE", -1, -1);
      lcd.setCursor(0, 1);
      lcd.print("Lid unlocked - reset");

      if (buttonClicked) {
        Serial.println("SYSTEM RESET TO IDLE STATUS");
        allOff();
        currentPhase = STATE_IDLE;
      }
      break;

    // ================= STATE EMERGENCY CUTOFF =================
    case STATE_CUTOFF:
      // Rapid blinking red LED as alarm
      digitalWrite(PIN_LED_RED, (millis() % 300 < 150) ? HIGH : LOW);
      digitalWrite(PIN_LED_GREEN, LOW);
      digitalWrite(PIN_LED_YELLOW, LOW);
      
      lcd.setCursor(0, 0);
      lcd.print("CRITICAL ERROR! ");
      lcd.setCursor(0, 1);
      lcd.print("OVERHEAT: ");
      lcd.print((int)temperature);
      lcd.print("C  ");

      if (buttonClicked) {
        // Enforce cooling wait period before allowing a manual override reset
        if (temperature < 50.0) {
          Serial.println("TEMPERATURE RESTORED TO SAFE THRESHOLD. SYSTEM RESETTABLE.");
          allOff();
          currentPhase = STATE_IDLE;
        } else {
          Serial.println("RESET ATTEMPT BLOCKED. SURFACE TEMPERATURE EXCEEDS SAFE 50C RETRY.");
          // Chirp buzzer as error warning
          digitalWrite(PIN_BUZZER, HIGH);
          delay(100);
          digitalWrite(PIN_BUZZER, LOW);
        }
      }
      break;
  }
}
```

---

## 5. Wiring and Connectivity Master Guide

| Wire Number | Pin / Connection | Wire Gauge (AWG) | Wire Color | Destination | Function |
|---|---|---|---|---|---|
| **1** | LM2596S OUT+ | 20 AWG | Red | Arduino Mega `5V` Pin | Regulated logic power supply (MUST calibrate to 5V beforehand) |
| **2** | LM2596S OUT− | 20 AWG | Black | Arduino Mega `GND` Pin | Common negative logic ground link |
| **3** | Mega Pin D2 | 22 AWG | Yellow | DHT22 DATA | Ambient chamber relative humidity input (10kΩ pull-up to 5V) |
| **4** | Mega Pin D3 | 22 AWG | Blue | DS18B20 DATA | Heater surface temperature reading (4.7kΩ pull-up to 5V) |
| **5** | Mega Pin D4 | 22 AWG | Red | SSR PTC 1 Trigger | LCTC DC-DC SSR 40A (HIGH = closes Station 1 PTC circuit) |
| **6** | Mega Pin D5 | 22 AWG | Orange | SSR Motor 1 Trigger | LCTC DC-DC SSR 10A (HIGH = turns on Worm Motor 1) |
| **7** | Mega Pin D6 | 22 AWG | Red | SSR PTC 2 Trigger | LCTC DC-DC SSR 40A (HIGH = closes Station 2 PTC circuit) |
| **8** | Mega Pin D7 | 22 AWG | Orange | SSR Motor 2 Trigger | LCTC DC-DC SSR 10A (HIGH = turns on Worm Motor 2) |
| **9** | Mega Pin D8 | 22 AWG | Red | SSR PTC 3 Trigger | LCTC DC-DC SSR 40A (HIGH = closes Station 3 PTC circuit) |
| **10** | Mega Pin D9 | 22 AWG | Orange | SSR Motor 3 Trigger | LCTC DC-DC SSR 10A (HIGH = turns on Worm Motor 3) |
| **11** | Mega Pin D10 | 22 AWG | White | PWM Blower Station 1 | `analogWrite(D10, val)` — 0–255 duty cycle control |
| **12** | Mega Pin D11 | 22 AWG | White | PWM Blower Station 2 | `analogWrite(D11, val)` — 0–255 duty cycle control |
| **13** | Mega Pin D12 | 22 AWG | White | PWM Blower Station 3 | `analogWrite(D12, val)` — 0–255 duty cycle control |
| **14** | Mega Pin D13 | 22 AWG | Purple | SSR Fan Bus Trigger | LCTC DC-DC SSR 40A (HIGH = closes master Fan Bus) |
| **15** | Mega Pin D14 | 22 AWG | Green | Arcade Button NO | Active-LOW trigger logic; button NC is unmapped |
| **16** | Mega Pin D15 | 22 AWG | Red | Status LED (Red) | Connected via series 220Ω current-limiting resistor |
| **17** | Mega Pin D16 | 22 AWG | Yellow | Status LED (Yellow) | Connected via series 220Ω current-limiting resistor |
| **18** | Mega Pin D17 | 22 AWG | Green | Status LED (Green) | Connected via series 220Ω current-limiting resistor |
| **19** | Mega Pin D18 | 22 AWG | White | Active Buzzer + | Emits cycle alerts (Audible notification) |
| **20** | Mega Pin D20 | 22 AWG | Green | LCD I2C SDA | Hardware SDA interface (pull-ups usually integrated on I2C board) |
| **21** | Mega Pin D21 | 22 AWG | Yellow | LCD I2C SCL | Hardware SCL interface (pull-ups usually integrated on I2C board) |
| **22** | Mega Pin D22 | 22 AWG | Brown | Lid Reed Switch | NO reed to GND; INPUT_PULLUP; lid closed = LOW (machine won't start while open) |
| **23** | Mega Pin D23 | 22 AWG | Pink | Solenoid Lock SSR (SSR-10A) IN+ | SSR IN− → GND; SSR COM → +12V, NO → solenoid +; HIGH pulse ~3 s = unlock |

---

## 6. Sourcing Software Dependencies

1. **DHT Sensor Library** by Adafruit (ver 1.4.x+)
2. **Adafruit Unified Sensor** by Adafruit (ver 1.1.x+)
3. **OneWire** by Paul Stoffregen (ver 2.3.x+)
4. **DallasTemperature** by Miles Burton (ver 3.9.x+)
5. **LiquidCrystal I2C** by Frank de Brabander (ver 1.1.2+)

> **No Servo library needed** — blowers use `analogWrite()` directly.

---

## 7. Debugging tips

| Symptom | Check |
|---|---|
| No blower response | Verify D10/D11/D12 wired correctly; `analogWrite(D, 255)` sends full PWM; fan bus SSR (D13) must be ON for 12V power |
| Blowers don't spin | Check 12V from fan bus SSR to blower VIN; check PWM signal from Mega with multimeter or oscilloscope |
| No humidity reading | DHT22 VCC→5V, GND→GND, DATA→D2 with 10kΩ pull-up; use the DHT22 **module**, not a bare sensor |
| No temperature reading | DS18B20 red→5V, black→GND, yellow→D3 with 4.7kΩ pull-up; run a OneWire scanner sketch |
| LCD blank / garbage | Try address 0x3F; call `lcd.init()`; on the **Mega, I2C is pins 20/21 — NOT A4/A5** |
| Heater SSR doesn't trigger | D4/D6/D8 → SSR IN+; SSR IN− → GND; COM → +12V, NO → heaters |
| Motor SSR doesn't trigger | D5/D7/D9 → SSR-10A IN+; SSR IN− → GND; COM → +12V, NO → motor |
| SSR energized but load stays off | Check the high-current side: 12V → output COM, load → output NO |
| Button not responding | D14 → button pin 1, pin 2 → GND; INPUT_PULLUP; LOW = pressed |
| Thermal cutoff triggers immediately | DS18B20 may be heated by direct contact — mount probe in the air stream, not touching heater body |
| Buck output not 5V | Adjust potentiometer with multimeter BEFORE connecting to Mega; must be 5.0V ± 0.1V |
| Motors spin wrong direction | Swap the two motor leads (DC motor direction = polarity) |
| Cycle won't start | **Lid is open** — the reed switch (D22) must read LOW (lid closed). Close the lid; if it still won't start, verify the reed wiring and that the magnet on the lid aligns with the reed housing |
| Lid stuck locked / won't open | Hold Start ~2 s in IDLE to pulse the solenoid (D23). Check the SSR input (IN+ → D23, IN− → GND) and the output path (+12V → SSR COM → SSR NO → solenoid + → GND). The lock is fail-secure and needs a 12 V pulse to release |

---

## 8. Staged operation (IMPORTANT — current budget)

One station's full load = 3 PTC (25A) + 3 blowers (13.5A) + motor (0.8A) + logic (0.5A) ≈ **39.3A**.
Staged operation keeps the worst-case draw at ≈ **39.3A** by running only one station at a time — well under the 200A BMS limit.

The firmware **always** operates in staged mode — heaters round-robin 30 s per station; only the active station's motor and blower PWM run. All other stations' PTC and PWM are OFF.

---

## 9. Safety notes

- The system runs on **12V DC only** — no mains voltage anywhere.
- Battery BMS protects against over-discharge, over-charge, and short circuit.
- DS18B20 thermal cutoff at 65°C is the primary software safety.
- PTC heaters are self-regulating — they auto-limit current as temperature rises.
- Over-temperature protection relies on PTC self-regulation and DS18B20 firmware 65°C cutoff. No thermal fuses.
- Over-current protection relies on BMS 200A cutoff and PTC self-regulation. No hardware fuses.
- SSR pins boot in their OFF state (floating/LOW = OFF). `setup()` calls `allOff()` first regardless.
- **Lid safety interlock:** the machine will not start a drying cycle while the lid is open (reed D22 must read LOW); the lid is locked shut for the whole cycle (solenoid D23) and only pulsed open at COMPLETE or on a 2 s hold while IDLE.
- **Fail-secure lock:** the solenoid lock is normally-locked — D23 LOW (or any 12 V power loss) keeps the lid shut. During a power loss mid-cycle the lid stays locked until power returns (all thermal/fan/motor loads are also off, so this is safe; hold Start ~2 s once power returns to open).
- Mega is powered ONLY from the calibrated buck via the 5V pin — never the barrel jack, never raw 12V.

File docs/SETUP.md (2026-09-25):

# Setup Guide — 12V DC

> Complete setup instructions for the 12V DC umbrella dryer. No mains wiring required.

---

## 1. Unbox and verify

- [ ] Battery bank: 1× LiFePO4 12.8V 200Ah with BMS
- [ ] Charger: 14.6V 20A LiFePO4 charger
- [ ] Mega 2560 clone + USB cable
- [ ] 4× LCTC DC-DC SSR 40A (for PTC heaters + fan bus) + 4× LCTC DC-DC SSR 10A (3 for motors + 1 for solenoid lock)
- [ ] 7× SSR heatsinks (~₱50 each)
- [ ] 9× PTC ceramic heaters (12V 100W) — verify 12V, not 220V!
- [ ] 9× AVC 12V DC blower fans (80×80×38mm, 4.5A) — verify 12V variant
- [ ] 3× SGM-370 worm gear motors
- [ ] 3× PETIYOUZA rigid flange coupling (6mm bore)
- [ ] 3× rigid shaft coupling 6×8mm (motor output shaft → shaft)
- [ ] 3× 304 SS shaft 6mm × 300mm (passes through the pillow block middle)
- [ ] 3× UCP06 pillow block bearing (6mm bore)
- [ ] DHT22 module, DS18B20 waterproof, LCD 16×2 I2C
- [ ] **Magnetic Door Reed Switch Set NO/NC** (Makerlab) — lid-closed sensor (with magnet)
- [ ] **Solenoid Lock 12VDC** (Makerlab) — lid bolt lock; 1N4007 flyback diode across its terminals
- [ ] LM2596S buck module
- [ ] LEDs (R/Y/G), buzzer, arcade button
- [ ] Wire kit (6–18 AWG silicone), connectors, heat-shrink
- [ ] Zip ties, M3/M4 screws, sealant, drip tray, velcro, grommets

---

## 2. Firmware upload

1. Install Arduino IDE.
2. Install libraries: DHT sensor library, OneWire, DallasTemperature, LiquidCrystal_I2C (Adafruit Unified Sensor is a dependency).
3. Open the sketch from `FIRMWARE-GUIDE.md` (copy the complete sketch into a new `.ino` file).
4. Select board: **Arduino Mega 2560**. Select correct COM port.
5. Upload. Open Serial Monitor at 115200 baud — should print "Umbrella Dryer V2 — 12V DC System Boot Initializing".

---

## 3. Buck module calibration (BEFORE connecting to Mega)

1. Disconnect buck output from Mega.
2. Connect buck input to 12V battery (or any 12V source).
3. Measure buck output with multimeter.
4. Turn potentiometer until output reads **5.0V ± 0.1V**.
5. **IMPORTANT:** On the Mega, connect buck OUT+ to the **5V pin** — NOT the barrel jack.
6. Disconnect 12V input. Now safe to wire to Mega.

---

## 4. Mechanical assembly

1. **Frame:** Build 3-station frame. Each station holds 1 umbrella inverted.
2. **Motor mounts:** Attach SGM-370 motors to aluminum plates. Align motor output shaft center with umbrella hub center.
3. **Drivetrain:** Per station, in order: SGM-370 motor → rigid coupling 6×8mm → 6mm × 300mm SS shaft → UCP06 pillow block (shaft passes through the bearing's middle) → PETIYOUZA 6mm-bore rigid flange coupling → umbrella hub. Motor and pillow block bolted to the 6mm aluminum plate.
4. **Verify:** Spin by hand. Should rotate freely with no binding. Motor is self-locking.
5. **Lid safety interlock:** Mount the **reed switch** housing on the chamber frame edge and its **magnet** on the front lid so the pair aligns (closes) when the lid is fully shut. Mount the **solenoid lock** bolt bracket on the frame and its strike on the lid so the bolt holds the lid shut when extended. Run the reed and solenoid wires through a rubber grommet into the control enclosure.

---

## 5. Wiring

### 5a. Power distribution

1. Connect battery positives (main link) and negatives (main link) — use 8 AWG.
2. Battery + → 2-pin screw terminal → **positive 150A bus bar** — 8 AWG.
3. From the **positive bus bar**, run branches:
   - Station 1 PTC: 10 AWG → LCTC DC-DC SSR 40A (D4) → 3 PTC heaters
   - Station 2 PTC: 10 AWG → LCTC DC-DC SSR 40A (D6) → 3 PTC heaters
   - Station 3 PTC: 10 AWG → LCTC DC-DC SSR 40A (D8) → 3 PTC heaters
   - Fan bus: 10 AWG → LCTC DC-DC SSR 40A (D13) → blower distribution
   - Motor 1/2/3: 18 AWG → LCTC DC-DC SSR 10A (D5/D7/D9) → SGM-370 motor
   - Lid solenoid lock: 20 AWG → LCTC DC-DC SSR 10A (D23) → solenoid lock
   - Logic: 20 AWG → buck module → 5V to Mega

### 5b. SSR wiring (for each LCTC DC-DC SSR — 8 total: 4× 40A + 4× 10A)

| SSR terminal | Goes to |
|---|---|
| IN+ | Mega pin (D4/D6/D8 for PTC, D13 for fan, D5/D7/D9 for motor, **D23 for the lid solenoid**) |
| IN− | GND |
| COM (input side) | +12V bus |
| NO (output side) | Load (heaters/fans/motors) |

Active-HIGH: `digitalWrite(pin, HIGH)` = SSR ON. Onboard optocoupler holds SSR OFF at boot.

### 5c. Blower PWM wiring

1. Each AVC blower has 2 power leads (red VIN 12V, black GND) + 1 PWM signal lead.
2. Connect VIN → fan bus distribution (switched 12V from the D13 SSR-40DD).
3. Connect GND → common ground rail.
4. Connect PWM signal → Mega D10 (station 1), D11 (station 2), D12 (station 3) — 3 leads per pin.

### 5e. Sensor wiring

1. DHT22: VCC→5V, GND→GND, DATA→D2 with 10kΩ pull-up to 5V.
2. DS18B20: Red→5V, Black→GND, White/Yellow→D3 with 4.7kΩ pull-up to 5V.
3. LCD I2C: VCC→5V, GND→GND, SDA→**D20**, SCL→**D21** (Mega I2C pins, NOT A4/A5).

### 5f. UI wiring

1. Arcade button: pin 1→D14, pin 2→GND (internal pull-up). LED ring: +→5V, −→GND.
2. LEDs: anode→D15(red)/D16(yellow)/D17(green) via 220Ω, cathode→GND.
3. Buzzer: +→D18, −→GND.

### 5g. Lid safety interlock wiring

**Reed switch (lid-closed sensor):**
1. Reed switch lead 1 → Mega **D22** (INPUT_PULLUP). Lead 2 → GND.
2. Use the **NO** contacts, and mount the magnet on the lid so it aligns with the reed housing when shut.
3. Fully closed lid = D22 reads **LOW** (contact closed). Open = HIGH.
> Verify: with the lid shut, `digitalRead(D22)` = LOW; the machine will **not start** while it reads HIGH.

**Solenoid lock (via the 4th SSR-10A on D23):**
1. SSR IN+ → Mega **D23**, SSR IN− → GND.
2. SSR COM (load side) → +12V bus (20 AWG).
3. SSR NO (load side) → solenoid lock **+** lead; solenoid **−** → GND.
4. Solder a **1N4007 flyback diode** across the solenoid terminals (banded/cathode end → solenoid **+**) to protect the SSR from inductive kickback.
> The lock is **normally-locked (fail-secure)**: D23 LOW (or power off) = bolt out = lid locked, 0 A draw. A ~3 s HIGH pulse on D23 retracts the bolt (unlock) — at cycle COMPLETE and when you hold Start ~2 s while IDLE to load.

---

## 6. Power-on test (no load)

1. **Disconnect all SSR outputs** (no PTC heaters, no motors, no fans yet).
2. Connect battery.
3. Buck LED should light. Measure 5V at Mega 5V pin.
4. Mega should boot. LCD shows "Umbrella Dryer V2 DC SYSTEM".
5. Blowers must stay OFF at boot — D13 (fan bus) stays LOW in IDLE; the onboard LED follows the fan-bus state.
6. After 2s, LCD settles on "SYSTEM READY / Press Button".
7. Press button → should enter PREHEAT phase on LCD.
8. Press again → should emergency stop back to IDLE.

---

## 7. Functional test (with loads)

1. Reconnect SSR outputs to PTC heaters, motors, and fans.
2. **Lid interlock check:** With the lid OPEN, tap Start → the cycle must be **refused** (buzzer + "CLOSE LID", stays IDLE). Close the lid → tap Start → cycle begins and the lid **locks shut** (D23 solenoid off = fail-secure; try the lid — it must not open).
3. Fans spin up, PTC heaters warm (feel heat after 30s).
4. Wait for the lid reed (D22) to confirm closed; wait for DHT22 to read ≥45°C → motor starts spinning (staged — one at a time).
5. During DRY, verify the lid cannot be opened (locked).
6. Timer counts down 15 min → enters COOL phase for 2 min.
7. Buzzer beeps 3× → COMPLETE and the **lid pulses UNLOCKED** (open the lid and retrieve). Tap Start to reset to IDLE.
8. **Loading check:** hold Start ~2 s in IDLE → the lid unlocks for ~3 s (open + load).

---

## 8. Thermal test

1. Run cycle. Monitor DS18B20 temperature on LCD.
2. Temperature should rise during PREHEAT/DRY (40–60°C expected).
3. Verify: if DS18B20 reads >65°C, everything should shut off (thermal cutoff).
4. Let system cool. Verify fans run during COOL phase.

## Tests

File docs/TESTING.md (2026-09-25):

# Testing Guide — 12V DC

> Test plan for the 12V DC umbrella dryer. No mains voltage — all tests on 12V DC battery power.

---

## 1. Test levels

| Level | What | Pass criteria |
|---|---|---|
| L1 — Smoke test | Power on with no loads | Buck outputs 5V, Mega boots, LCD shows "READY", SSRs idle |
| L2 — Component test | Each subsystem individually | Each SSR triggers, each blower spins, each motor rotates, sensors read values, lid interlock asserts (refuses start when open, unlocks at COMPLETE) |
| L3 — Integration test | Full cycle with loads | PREHEAT → DRY → COOL → COMPLETE completes; safety cutoff works; lid locks during cycle and unlocks at COMPLETE |
| L4 — Stress test | Extended run | Battery drains correctly, no overheating, SSR ratings adequate |

---

## 2. L1 — Smoke test

1. Disconnect all SSR outputs (no PTC, no motors, no blowers).
2. Connect battery.
3. **Check:**
   - [ ] Buck LED lights, output = 5.0V at Mega **5V pin** (NOT barrel jack)
   - [ ] Mega boots, Serial Monitor prints "Umbrella Dryer V2"
   - [ ] LCD shows "Umbrella Dryer V2 DC SYSTEM"
   - [ ] LCD settles on "SYSTEM READY / Press Button"
   - [ ] All SSR pins are LOW (no clicking)
4. If anything fails → check wiring, buck voltage, I2C address (try 0x3F), **LCD on Mega pins 20/21**.

---

## 3. L2 — Component tests

### 3a. SSR test

1. Connect only SSR modules (no loads on COM/NO).
2. Press button → PREHEAT phase.
3. **Check:**
   - [ ] D4 goes HIGH → station 1 PTC SSR energizes (ON indicator lights)
   - [ ] D13 goes HIGH → fan bus SSR energizes ON (blowers will spin)
4. Wait for DRY phase:
   - [ ] D5 goes HIGH → station 1 motor SSR energizes ON
   - [ ] After 30s rotation: D5→OFF, D6→HIGH (station 2 PTC), D7→HIGH (station 2 motor)
5. COOL phase: all SSRs OFF, blowers stay ON.
6. If PTC SSR doesn't trigger → check D4 connection to SSR IN+; IN− → GND; COM → +12V, NO → heaters.
7. If motor SSR doesn't trigger → check D5 → SSR IN+; SSR IN− → GND; COM → +12V, NO → motor.

### 3b. Blower PWM test

1. Connect one AVC blower: red (VIN) → 12V, black (GND) → GND, signal → D10.
2. Upload sketch. Press button → PREHEAT → blower should spin at full speed.
3. **Check:**
   - [ ] Blower spins smoothly at full speed (`analogWrite(D10, 255)`)
   - [ ] No unusual vibration or noise
   - [ ] Blower stops when `analogWrite(D10, 0)` in COOL/DONE
   - [ ] Speed varies with `analogWrite(D10, val)` — 128 = half speed
4. Repeat for D11 (station 2) and D12 (station 3).

### 3c. Motor test

1. Connect one SGM-370 motor to SSR-10A output.
2. Press button → DRY phase → staged rotation → D5 goes HIGH for station 1.
3. **Check:**
   - [ ] Motor rotates at ~6 RPM
   - [ ] Direction: umbrella should spin (reverse any two leads if wrong)
   - [ ] Motor stops when SSR OFF (D5 goes LOW)
   - [ ] Motor holds position when off (self-locking)

### 3d. Sensor test

1. DHT22: Serial Monitor should print humidity % and temperature °C.
2. DS18B20: Serial Monitor should print temperature.
3. **Check:**
   - [ ] DHT22 reads 30–80% humidity
   - [ ] DS18B20 reads 20–35°C (ambient)
   - [ ] Values update every 500ms

### 3e. Button test

1. Press button → should start cycle (IDLE → PREHEAT).
2. Press again during PREHEAT → should emergency stop (back to IDLE).
3. **Check:**
   - [ ] No false triggers from noise
   - [ ] Button responsive within 300ms

### 3f. Lid interlock test

1. With the lid **OPEN**, tap Start → the cycle must be **refused** (LCD: "CLOSE LID", 3 warning beeps, stays IDLE).
2. Close the lid → tap Start → cycle should begin; LCD shows "PREHEAT".
3. While the cycle is running, try opening the lid → all loads must kill immediately (lid-open safety interlock) and the system returns to IDLE.
4. After COMPLETE, the lid should pulse **UNLOCKED** (open it freely).
5. In IDLE, hold Start ~2 s → the lid should unlock for ~3 s (pulse to load), then re-lock.

---

## 4. L3 — Integration test (full cycle)

1. Connect all loads: PTC heaters, motors, blowers.
2. Place umbrellas on stations.
3. Press button → observe full cycle:

| Phase | Expected | Time |
|---|---|---|
| PREHEAT | Blowers spin, PTC warm, staged station rotation every 30s | Until DS18B20 ≥ 45°C |
| DRY | Motor spins umbrella (staged), blowers + PTC stay on | Max 15 min — ends early at ≤ 60% RH (after ≥ 3 min) |
| COOL | Motor off, PTC off, blowers run for cooling | 2 min |
| COMPLETE | Everything off, buzzer beeps 3×, LED green | Until button press |

4. **Check:**
   - [ ] Umbrella fabric dries (no wet spots after cycle)
   - [ ] No burning smell from PTC heaters
   - [ ] Temperature stays 40–60°C during DRY phase
   - [ ] Thermal cutoff does NOT trigger during normal operation
   - [ ] Staged rotation verified: only one station's PTC + motor + blower ON at a time
   - [ ] Blower PWM works at full speed during PREHEAT/DRY
   - [ ] Humidity auto-stop: with a dry chamber (RH ≤ 60%), DRY ends before the 15-min timer
   - [ ] Min-dry guard: a wet load keeps RH > 60% → DRY runs the full 15 min

---

## 5. L4 — Stress test

1. Run 3 consecutive cycles (30 min each, 90 min total).
2. **Check:**
   - [ ] Battery voltage stays above 12.0V after 3 cycles
   - [ ] No component overheats (touch test: motor, SSR, PTC mounting)
   - [ ] SSR heatsinks remain within safe temperature
   - [ ] Buck output stable at 5.0V throughout
   - [ ] LCD remains readable

---

## 6. Safety test

1. **Thermal cutoff:** Hold DS18B20 probe near a heat source (hair dryer). When reading exceeds 65°C → everything should shut off immediately. LCD shows "CRITICAL ERROR! OVERHEAT: XXC". Pressing button should only reset if T < 50°C.
2. **Battery BMS:** Run until BMS disconnects (low voltage protection). Verify system shuts down gracefully.
3. **Blower PWM safety:** Confirm that blowers respond correctly to `analogWrite()` — no runaway speed at any duty cycle.

---

## 7. Pass/fail checklist

| Test | Pass | Fail | Notes |
|---|---|---|---|
| L1: Smoke test | | | |
| L2a: SSRs (PTC + motor + fan bus) | | | |
| L2b: Blower PWM | | | |
| L2c: Motors | | | |
| L2d: Sensors | | | |
| L2e: Button | | | |
| L3: Full cycle (staged) | | | |
| L4: Stress (3 cycles) | | | |
| Safety: Thermal cutoff | | | |
| Safety: BMS | | | |
| Safety: Lid interlock — refuse start when open | | | |
| Safety: Lid interlock — lock during cycle, unlock at COMPLETE | | | |

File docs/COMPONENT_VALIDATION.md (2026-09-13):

# Smart Umbrella Dryer — Component & Material Validation (Rev 4)

**Revision 4 — design changes from Rev 2:** Fotek SSR-25DD + BTS7960 **replaced by optocoupler relay modules** (heater and motors only need on/off switching — saves ~₱1,900) · water pump and MOSFET **removed** (gravity drain) · **MLX90614 IR sensor removed from the design** · **single-motor carousel replaced by 3 independent worm-gear-motor stations (one motor per umbrella)** · system re-verified for **3 umbrellas simultaneously**.

## Study Overview

**Title:** Smart Umbrella Dryer: Design and Development of a Multi-Umbrella Drying System with Energy Efficient Control

**Key Requirements:**
1. Dry **3 umbrellas** simultaneously (any 1–3 mix per cycle)
2. Energy-efficient operation (battery backup support)
3. Smart/automated control via sensors
4. Safe operating temperatures for umbrella materials

---

## 0. Change Summary (v2 → v4)

| Change | Rev 2 | Rev 4 | Reason |
|---|---|---|---|
| Heater switching | Fotek SSR-25DD (₱1,800) | **1-CH 30A relay module w/ optocoupler (₱113)** | On/off + slow duty cycling only — a relay contact does the job |
| Motor driver | BTS7960 43A (₱305) | **2× 2-CH relay modules w/ optocoupler (₱178)** | 16 RPM fixed is the design speed — no PWM needed |
| Rotation | 1 worm motor driving a shared carousel | **3× worm gear motors — one per umbrella station** | Independent stations: any 1–3 umbrellas, per-station control, no imbalance across a crossbar |
| Water pump | REMOVED | REMOVED — gravity drain + drip tray | Pump was the only flood-failure component |
| MLX90614 IR sensor | Optional (kept) | **REMOVED from the design** | Non-essential; DHT22 + DS18B20 fully cover the control loop |
| Main fuse | 20A | **25A** | 3-motor stall worst case exceeds 20A headroom at battery sag |
| Motor-branch fuses | 5A (shared) | **3A per station (×3)** | One jammed station cannot take down the others |
| Capacity target | 3 umbrellas (shared carousel) | 3 umbrellas — **independent stations** | Study requirement |

---

## 1. Microcontroller — Arduino Mega 2560 ✅ UNCHANGED

| Parameter | Value |
|---|---|
| Processor | ATmega2560 |
| Digital I/O | 54 (15 PWM) |
| Analog pins | 16 |
| Flash / SRAM | 256 KB / 8 KB |
| Clock | 16 MHz |
| I2C | SDA=20, SCL=21 |

**v4 pin audit:** heater relay (1) + 3 motor relays (3) + 3 station status LEDs (3) + buzzer + start button + LCD I2C + 2 sensors ≈ **11 digital + 2 I2C** — far inside the Mega's capacity. ✅ COMPATIBLE

**Powering the Mega:** Makerlab's Mega listing explicitly warns *"do not supply with 12V on DC jack"*. Feed the Mega from the **LM2596S 5V output → Mega 5V pin** (or USB), not the DC jack from battery voltage.

Listing: `makerlab.ph/products/mega-2560-r3-with-usb-cable-compatible-with-arduino-do-not-supply-with-12v-on-dc-jack` — ₱1,199

---

## 2. Power Supply — LiFePO4 12.8V 30Ah w/ BMS (PowMr) — REPLACED ExpertPower 35Ah

ExpertPower 35Ah (the paper's original pick) is not stocked on Lazada PH; the PowMr 12.8V 30Ah is the verified local equivalent: **384 Wh, BMS with 30A max continuous discharge** (per PowMr's published spec sheet), overcharge/over-discharge/short/over-temp protection.

**Worst-case draw check:** heater 8.3A + 3 motors at stall 10.5A + fan 0.25A + logic ~0.2A ≈ **13.1A peak** → BMS 30A = **2.3× margin**. ✅ (Stall is transient — seconds per start.)

**Fuse plan (v4):**

| Branch | Load | Fuse |
|---|---|---|
| Main battery line | 13.1A worst case | **25A** |
| Heater branch (through 30A relay) | 8.3A | 15A |
| Motor branch ×3 (one per station) | 1.2A rated / 3.5A stall each | **3A each** |
| Logic branch (LM2596S) | ~0.5A | 3A |

Wire gauge: **16 AWG** main + heater (8.3A), **18 AWG** motor branches (stall 3.5A), **22 AWG** sensors/logic.

---

## 3. Heating — PTC 12V 100W Air Heater Fan — switched by 30A relay module

Self-regulating ceramic PTC (auto-limits at Curie point), integrated blower, **8.3A @ 12V** (100W). Air at 40–60°C dries umbrella fabric (nylon/polyester) safely. Lazada's max 12V variant is 100W (no 120W exists — cycle runs ~20% longer than the Rev 2 math; see §9b). See §9 for 3-umbrella thermal verification.

**1-CH 30A relay module integration details**

| Parameter | Value | Design check |
|---|---|---|
| Contact rating | 30A @ 30VDC | 3.6× the 8.3A heater ✅ |
| Coil | 5V, ~70mA, driven from LM2596S rail | NOT from a Mega pin ✅ |
| Input | optocoupler LED, low-level trigger, ~2–5mA | direct Mega pin (≤20mA source) ✅ |
| Flyback | built-in diode on coil + opto isolation | no transient paths to logic ✅ |

**Duty-cycle strategy:** **slow time-proportional control** (2–5s period) on a plain digital pin. Mechanical relays tolerate slow cycling; do NOT use fast PWM (490Hz+) — contact arcing and wear will destroy the relay.

---

## 4. Sensors — DHT22 + DS18B20 ✅ (MLX90614 REMOVED)

| Sensor | Role | Interface | Status |
|---|---|---|---|
| **DHT22 (AM2302)** | Chamber humidity — core feedback for duty cycling + auto-shutoff | 1-wire digital, D2 | Required — ₱69 (FU-LABS module) |
| **DS18B20 waterproof** | Heater-zone air temp — redundant over-temp cutoff | 1-Wire, D3 + 4.7kΩ pull-up | Required — ₱105 (Circuitrocks) |
| ~~MLX90614~~ | ~~Non-contact umbrella surface temp~~ | ~~I2C~~ | **REMOVED from the design** — surface temp is inferable from chamber air temp + cycle model; frees an I2C address and ~₱1,349 |

The I2C bus now carries only the LCD (0x27/0x3F). ✅ No conflicts.

---

## 5. Motor & Drive — 3× worm gear motors, one per station (Rev 4 core change)

### 5a. Motors: 3× DC Worm Gear Motor SGM-A58SW31ZY, 12V, 16RPM (makerlab.ph, ₱1,249 each)

| Parameter | Value |
|---|---|
| Voltage range / rated | 6–12V / 12V |
| No-load speed / current | 16 RPM / 240mA |
| **Rated load** | 11 RPM @ **1.2A**, **60 kg·cm torque** |
| Stall torque / stall current | **70 kg·cm** / 3.5A |
| Shaft | **8mm diameter × 15mm** |
| Body | 115×40×35.7mm, 357g |

Why one motor per umbrella (vs Rev 2/3's single shared-carousel motor):
- **Independent stations** — any 1–3 umbrellas can be dried per run; per-station start/stop as each umbrella dries.
- **Load per motor drops to ≤3 kg·cm** (one umbrella + holder, worst case) → **≥20× torque margin** (Rev 3 shared-carousel math needed 8–10 kg·cm against one 60 kg·cm motor).
- **Fault isolation** — a jammed umbrella stalls one motor only; the other stations keep running, each protected by its own 3A fuse.
- **No crossbar imbalance** — each station carries only its own umbrella; mounting positions no longer affect torque.
- **Self-locking** — the worm cannot be back-driven, so each station holds position when off.
- 16 RPM direct = gentle rotation (no centrifugal water loss); no external reduction.

Variant notes: 80RPM variant (₱1,299) available; dual-shaft +₱50. Recommended: **Single Shaft 16RPM (₱1,249) ×3 — order all three from makerlab.ph in one order.** The Lazada JGY370 (~25 kg·cm, different shaft) is NOT an acceptable substitute.

Listing: `makerlab.ph/products/dc-worm-gear-motor-sgm-a58sw31zys-12v-16rpm-80rpm-sgm-370-12v-40rpm-160rpm-dc-motor`

### 5b. Drivers: 2× 2-CH relay modules w/ optocoupler (₱89 each) — REPLACED BTS7960

- 3 of the 4 channels drive the motors (1.2A rated / 3.5A stall vs 10A@30VDC contacts → **2.9× margin at stall** per channel). ✅
- 4th channel drives the 120mm circulation fan (0.25A). ✅
- Relay coils from the LM2596S 5V rail; Mega drives only the optocoupler LEDs (~2–5mA per channel). ✅
- Each motor channel sits in its own 3A-fused station branch — a stalled motor pops only its own fuse. ✅
- Lost vs BTS7960: PWM speed control (not needed — 16 RPM is the design speed) and current-sense telemetry (replaced by per-station fuse + relay-state logic: a drawn 3A fuse with the relay commanded on = jam indication at the UI).

### 5c. Mechanical transmission — 3 independent stations

| Component | v4 spec | Note |
|---|---|---|
| Steel shaft | **3× 8mm × 300mm** (304 SS, ground) | one per station; 8mm system-wide matches motor shaft & KP08 bore |
| Pillow block bearing | **6× KP08** (2 per station) | radial rating ≫ single-umbrella load; >30× margin |
| Shaft coupling | **3× 8×8 rigid** (2 sets cover it + spare) | motor 8mm shaft × station 8mm shaft |
| Umbrella holder | **3× holders, one per station shaft** | aluminum plate fabrication |

---

## 6. Voltage Regulation — LM2596S ✅ UNCHANGED

12.8V → 5V @ 3A. v4 logic load: Mega (~0.2A) + DHT22 + DS18B20 + LCD (~0.04A) + LEDs + buzzer + **4 relay coils (~70mA each = 0.28A)** ≈ **0.7–0.8A** — still only ~27% of the 3A rating. Power the Mega via its **5V pin**, not the DC jack. ✅ (Rev 3 estimate was 0.45A; the added relay coils are the difference — still comfortable.)

---

## 7. Water Management — PASSIVE (pump removed) ✅ UNCHANGED

1. **Chamber floor sloped ~3–5°** toward one corner.
2. **Slotted drain hole + silicone drain tube** exiting the chamber wall.
3. **Removable drip tray** outside the chamber base — emptied per use (3 umbrellas shed roughly 100–300mL per cycle; a 500mL tray covers it).
4. Optional: hydrophobic mesh liner on the floor so drips funnel to the drain.

Trade-off accepted: condensate removal is manual (empty the tray) in exchange for a simpler, cheaper, fault-free chamber. The humidity-based auto-shutoff logic is unaffected. ✅ COMPATIBLE

---

## 8. User Interface ✅ UNCHANGED (minus MLX90614)

- **LCD 16×2 I2C** (₱165, addr 0x27/0x3F) — sole I2C device now.
- **LEDs:** green = ready/complete, yellow = drying, red = error/over-temp (station status ×3 + system).
- **Piezo buzzer:** cycle-complete alert, direct from a Mega pin.
- **Momentary push button** (INPUT_PULLUP): start/reset cycle.
- **Rocker switch:** hardware main power battery→fuse — also the manual kill for a fail-short heater relay.

---

## 9. THREE-UMBRELLA CAPACITY VERIFICATION ⭐ (Rev 4: three stations)

### 9a. Mechanical — per-station torque ✅ PASS

| Quantity | Value | Check |
|---|---|---|
| Rotating mass per station | 1 umbrella (0.4–0.7kg) + holder ≈ **1.2–1.7kg** | KP08 dynamic load ≈ 160kgf → >90× margin ✅ |
| Bearing friction torque per station | ≈ μ·F·r ≈ 0.003 × 15N × 0.01m ≈ **0.05 kg·cm** | — |
| Design allowance per station (imbalance, seal drag, wet fabric, startup) | ≈ **≤3 kg·cm** | — |
| Motor rated torque (each station) | **60 kg·cm** | **≥20× margin** ✅ |
| Stall torque | 70 kg·cm | tolerates a jammed umbrella ✅ |
| Rotation speed | 16 RPM direct | gentle, no centrifugal water loss ✅ |
| Station independence | any 1–3 stations run per cycle | matches the multi-umbrella study claim ✅ |

### 9b. Thermal — heater sizing ✅ PASS (100W, realistic cycle time)

| Quantity | Value |
|---|---|
| Water retained per umbrella (after shaking, open in chamber) | ≈ 30–100g (folding) up to 150g (golf) |
| Water for 3 umbrellas | ≈ **90–300g typical** (worst case 450g soaked) |
| Latent heat of vaporization | ≈ 2,260 J/g |
| Evaporation energy needed | 90g → 57Wh · 300g → 188Wh · 450g → 283Wh |
| PTC heat delivered | 100W, chamber transfer ~70–85% → **≈ 70–85W effective** |
| Cycle time (all 3 simultaneously) | **≈ 50 min (light rain) → ~2.5 h (fully soaked)**, humidity sensor auto-stops at threshold |

**Verdict: 100W PTC dries 3 umbrellas simultaneously in ≈50–150 minutes** with per-station rotation + forced air at 40–60°C. Slower than commercial 400–1000W spinner dryers — by design: the study's core claim is **energy-efficient control**. Per-station motors add a small benefit: late-finishing umbrellas can stop rotating, trimming parasitic motor losses. **Recommendation: keep 1× 100W heater.**

### 9c. Electrical — simultaneous worst-case ✅ PASS

| Load | Current @12V | Notes |
|---|---|---|
| PTC heater (relay ON) | 8.3A | 100W |
| Worm motors | 3.6A rated (10.5A stall, seconds) | 3 × 1.2A |
| 120mm fan | 0.25A | 3W |
| Relay coils (4) | 0.28A | from 5V rail ≈ 0.06A reflected on 12V |
| Logic (via LM2596S, 5V ~0.5A) | ≈ 0.22A | 2.8W |
| **Total steady (heater ON, 3 motors running)** | **≈ 12.5A ≈ 155W** | BMS 30A → 2.4× margin ✅ |
| **Peak (3 motor stalls + heater on)** | ≈ 13.1A (≈15.6A at 10.5V sag) | < 25A main fuse ✅ |

---

## 10. Runtime on Battery (3-umbrella cycles)

Energy available: **384Wh** (30Ah × 12.8V). Typical 3-umbrella cycle ≈ 70 min at ~60% heater duty:

| Scenario | Avg power | Runtime |
|---|---|---|
| Everything full-on (155W) | 155W | ≈ **2.5 h** |
| Typical cycle (~60% duty) | ≈ 95W | ≈ **4.0 h → ~3–4 full cycles per charge** |
| Aggressive duty cycling (30%) | ≈ 52W | ≈ 7.4 h |

**Energy per 3-umbrella cycle ≈ 90–95Wh ≈ ₱0 equivalent from battery** — the headline number for the study's energy-efficiency chapter.

---

## 11. System Block Diagram

```mermaid
flowchart TB
    subgraph POWER["Power domain"]
        BAT["Battery 12.8V 30Ah LiFePO4 with BMS 30A"]
        SW["Rocker switch main power"]
        F1["Fuse 25A main"]
        F2["Fuse 15A heater branch"]
        FM1["Fuse 3A station 1"]
        FM2["Fuse 3A station 2"]
        FM3["Fuse 3A station 3"]
        BUCK["LM2596S buck to 5V"]
    end

    subgraph LOADS["Power loads"]
        RH["1-CH 30A relay - heater"]
        PTC["PTC heater 12V 100W with blower"]
        RM["2x 2-CH relay modules - 3 motor ch + 1 fan ch"]
        M1["Worm motor station 1 - 60kg-cm 16RPM"]
        M2["Worm motor station 2 - 60kg-cm 16RPM"]
        M3["Worm motor station 3 - 60kg-cm 16RPM"]
        FAN["120mm circulation fan 12V"]
    end

    subgraph SENSE["Sensing and user interface"]
        DHT["DHT22 humidity + temp"]
        DS18B["DS18B20 waterproof probe"]
        LCD["LCD 16x2 I2C"]
        HMI["LEDs x3 stations + buzzer + start button"]
        DRAIN["Gravity drain + drip tray - passive"]
    end

    MEGA["Arduino Mega 2560"]

    BAT --> SW --> F1
    F1 --> F2 --> RH --> PTC
    F1 --> FM1 --> M1
    F1 --> FM2 --> M2
    F1 --> FM3 --> M3
    F1 --> FAN
    F1 --> BUCK --> MEGA
    MEGA -- "1 heater on-off" --> RH
    MEGA -- "2 motor on-off x3 + fan" --> RM
    MEGA -- "3 status outputs" --> HMI
    HMI -- "4 start button" --> MEGA
    DHT -- "5 humidity" --> MEGA
    DS18B -- "6 heater temp" --> MEGA
    MEGA <-. "7 I2C display" .-> LCD
    DRAIN -. "passive condensate" .- PTC
```

---

## 12. Compatibility Matrix (v4)

| Component | Voltage | Current margin | Interface | 3-umbrella fit | Verdict |
|---|---|---|---|---|---|
| Arduino Mega 2560 | 5V via buck | ✅ | 11 dig + 2 I2C | ✅ | ✅ PASS |
| LiFePO4 12.8V 30Ah (PowMr) | 12V native | 2.4× BMS margin | — | ✅ 3–4 cycles | ✅ PASS |
| PTC 100W heater | 12V | 8.3A | via 30A relay | ✅ 50–150min cycle | ✅ PASS |
| 1-CH 30A relay (heater) | 30VDC contacts | 3.6× (30A vs 8.3A) | optocoupler LED | ✅ | ✅ PASS |
| 2× 2-CH relays (motors + fan) | 30VDC contacts | 2.9× at stall per ch | optocoupler LED | ✅ 1 ch per motor | ✅ PASS |
| **3× worm motors 60kg·cm** | 12V | ≥20× torque margin per station | relay on/off | ✅ one per umbrella | ✅ PASS |
| LM2596S | 12.8→5V | 3.75× (3A vs 0.8A) | — | ✅ | ✅ PASS |
| DHT22 / DS18B20 | 3.3–5.5V | mA | 1-wire / 1-Wire | ✅ | ✅ PASS |
| LCD I2C + LEDs + buzzer + button | 5V | ✅ | I2C + digital | ✅ | ✅ PASS |
| 3× KP08 pairs + 8mm shafts + 8×8 couplings | N/A | >90× load per station | 8mm system | ✅ 3 stations | ✅ PASS |
| Gravity drain + drip tray (no pump) | N/A | N/A | passive | ✅ 100–300mL/cycle | ✅ PASS |

---

## 13. Safety Validation (v4)

| Hazard | Mitigation | Status |
|---|---|---|
| Overheating | PTC self-regulation + DS18B20 software cutoff | ✅ dual protection |
| **Heater relay fail-short** (heater stuck on) | Rocker switch (hard kill) + 15A branch fuse + PTC self-regulating | ✅ triple backup |
| Relay coil/transient noise | Optocoupler isolation + built-in flyback diodes | ✅ |
| Overcurrent | 25A main + branch fuses (15A heater, 3A ×3 stations, 3A logic) | ✅ |
| Battery overdischarge | PowMr BMS | ✅ |
| **Single-station jam** | Only that station's 3A fuse blows; other stations keep drying; worm drive stall-rated 70 kg·cm | ✅ fault isolation |
| Fire risk | PTC self-limiting (no open element) + all-extra-low-voltage 12VDC | ✅ low |
| Water accumulation | Gravity drain + drip tray (manual empty) | ✅ managed |
| Electrical shock | 12V DC system (extra-low voltage) | ✅ safe |
| Relay contacts on AC | 30VDC-rated contacts — mains use prohibited by design | ✅ documented |

---

## 14. Bill of Materials (v4 summary)

Full verified listings in `BOM.md` / `docs/PROCUREMENT.md`. Key figures:

| Group | Est. cost |
|---|---|
| Electronics (Mega, 3 relay modules, sensors, UI, buck, heater, fan) | ≈ ₱2,816 |
| Wiring, fuses, interconnect | ≈ ₱819 |
| Drivetrain — 3 stations (3× motor + 3× shaft + 6× KP08 + couplings) | ≈ ₱5,510 |
| Battery + charger (PowMr 30Ah + FOXSUR) | ≈ ₱4,445–5,445 |
| Chassis + consumables | ≈ ₱1,300 |
| **TOTAL (core)** | **≈ ₱14,890–15,890** (battery ≈ a third) |

---

## 15. Pin Map (v4 final)

| Pin | Connection |
|---|---|
| D2 | DHT22 data |
| D3 | DS18B20 data (+4.7kΩ pull-up to 5V) |
| D4 | Heater 30A relay input (optocoupler LED) — time-proportional duty (2–5s period) |
| D5 | Motor relay ch1 — station 1 |
| D6 | Motor relay ch2 — station 2 |
| D7 | Motor relay ch3 — station 3 |
| D8 | Fan relay ch4 (2nd 2-CH module) |
| D9 / D10 / D11 | Green / Yellow / Red LEDs (station 1; replicate pattern on D22–D27 for stations 2–3) |
| D12 | Piezo buzzer |
| D13 | Start/Reset push button (INPUT_PULLUP) |
| 20 / 21 (SDA/SCL) | LCD 16×2 I2C (sole I2C device) |
| GND | common ground rail (all relay inputs, sensors) |
| — | Rocker switch + 25A main fuse: battery → distribution |

---

## 16. Final Verdict (Rev 4)

### ✅ THE v4 SYSTEM IS COMPATIBLE AND CAN DRY 3 UMBRELLAS PER CYCLE — ON THREE INDEPENDENT STATIONS

- **Relay architecture** (1× 30A heater relay + 2× 2-CH motor/fan relays, all optocoupler-isolated) safely switches every load; slow duty cycling only.
- **3× worm gear motors (60 kg·cm each)** — one per umbrella — give ≥20× torque margin per station, fault isolation via per-station 3A fuses, and self-locking position hold.
- **MLX90614 removed** — the DHT22 + DS18B20 pair fully covers the control loop; I2C carries only the LCD.
- **25A main fuse** sized for the 3-motor stall worst case; BMS 30A has 2.4× margin.
- **3-umbrella cycle:** ≈50–150 min (humidity auto-shutoff), ≈90–95Wh per cycle, **3–4 cycles per battery charge**.
- All-12V extra-low-voltage safety, triple heater-failure backup, passive condensate handling.

---

*Related: `../references/FINALFINAL_SUD_CHAPTER-1-3.docx` (paper chapters 1–3). Figures affected by Rev 4 for the paper's next revision: Fig 11 (single motor → 3× worm gear motor stations), Fig 12 caption (BTS7960 → relay modules), **Fig 19 (DC water pump — remove)**, add new figure for the 30A relay module, **remove MLX90614 from Fig 10 and the I2C diagram**, update block diagram to 3 stations + 25A main fuse.*

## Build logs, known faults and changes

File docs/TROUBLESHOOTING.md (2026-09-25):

# Troubleshooting — 12V DC

> All voltages are 12V DC or 5V logic. No mains voltage in this system.

---

## 1. Power issues

| Symptom | Likely cause | Fix |
|---|---|---|
| Nothing turns on | Rocker switch off / battery cable loose | Flip the 50A rocker ON; check battery terminals and the 2-pin screw terminal |
| Buck LED off | Battery dead / input wiring loose | Measure battery voltage (>12.0V); check the buck input taps on the positive bus |
| Buck output ≠ 5V | Potentiometer misadjusted | Re-calibrate buck with multimeter BEFORE connecting to Mega 5V pin |
| Mega won't boot | Buck not providing 5V | Verify 5V at Mega **5V pin** (NOT barrel jack); check GND continuity |
| Battery dies fast | Too many stations running | Run staged operation (one at a time); check for shorts |

---

## 2. Sensor issues

| Symptom | Likely cause | Fix |
|---|---|---|
| DHT22 reads NaN | Wiring / library issue | Check VCC→5V, GND→GND, DATA→D2 with 10kΩ pull-up; use DHT22 **module** |
| DHT22 reads 0% or 100% | Damaged sensor or wiring | Replace DHT22; verify no solder bridges |
| DS18B20 reads −127°C | Bad connection / missing pull-up | Check white wire→D3 with 4.7kΩ pull-up; run OneWire scanner |
| DS18B20 reads 85°C only | Power issue (parasitic mode) | Connect VCC (red wire) to 5V |
| Temperature too high / low | Probe placement | Mount DS18B20 in heater air stream, not on metal surface |

---

## 3. LCD issues

| Symptom | Likely cause | Fix |
|---|---|---|
| LCD blank | Wrong I2C address | Try 0x3F instead of 0x27; use I2C scanner sketch |
| LCD shows squares | I2C not initialized | Call `lcd.init()` not `lcd.begin()`; **on Mega, I2C is pins 20/21 — NOT A4/A5** |
| LCD flickers | Loose connection | Check VCC, GND, SDA→D20, SCL→D21; reseat wire connections |

---

## 4. PTC SSR issues (SSR-40DD, D4/D6/D8)

| Symptom | Likely cause | Fix |
|---|---|---|
| PTC heaters stay cold | SSR input not driven | Check: D4/D6/D8 → SSR IN+, SSR IN− → GND; measure ~5V at IN+ when the pin is HIGH |
| SSR input powered, heaters still off | Output side miswired | Verify +12V bus → SSR output COM, heaters → output NO; reseat the 10 AWG heater leads |
| Heaters flicker on/off | Loose input jumper | Reseat IN+/IN− wires; check the Mega pin header |
| SSR overheats / shuts down | Heatsink missing or dry | Mount the SSR Heatsink BLACK with thermal paste; keep ≤25A per 40A SSR |
| SSR stays ON at boot | Firmware not writing safe states | Verify `allOff()` runs first in `setup()` |

---

## 5. Motor SSR issues (SSR-10A, D5/D7/D9)

| Symptom | Likely cause | Fix |
|---|---|---|
| Motor stays off | SSR input not driven | Check D5/D7/D9 → SSR IN+, IN− → GND; ~5V at IN+ when commanded |
| Motor stays off (input OK) | Output side miswired | Verify 18 AWG motor branch → SSR output side; motor + → the other output terminal |
| Motors spin wrong direction | Swap the two motor leads (DC motor direction = polarity) |
| Cycle won't start / start blocked | **Lid is open** — the reed switch (D22) must read LOW (lid closed). Close the lid; if it still won't start, verify the reed wiring and that the magnet on the lid aligns with the reed housing |
| Lid stuck locked / won't open | Hold Start ~2 s in IDLE to pulse the solenoid (D23). Check the SSR input (IN+ → D23, IN− → GND) and the output path (+12V → SSR COM → SSR NO → solenoid + → GND). The lock is fail-secure and needs a 12 V pulse to release |
| Motor hums but doesn't spin | Coupling misaligned / shaft binding | Loosen rigid + flange couplings; realign motor → shaft → hub; check the shaft spins freely in the UCP06 pillow block |

---

## 6. Fan bus issues (SSR-40DD, D13)

| Symptom | Likely cause | Fix |
|---|---|---|
| All 9 blowers dead | Fan bus SSR off / miswired | Measure 12V at the blower distribution block after D13 goes HIGH; check SSR output side |
| Bus powered, one blower dead | That blower's wiring | Check its VIN/GND pigtails and PWM lead |
| D13 LED (built-in Mega) doesn't blink | Firmware not driving D13 | Verify `allOff()` / `fansOn()` functions |

---

## 7. Blower PWM issues (D10/D11/D12)

| Symptom | Likely cause | Fix |
|---|---|---|
| Blower doesn't spin | PWM duty 0 or fan bus off | Raise `analogWrite(D10–D12, …)`; confirm D13 HIGH |
| Blower spins then stops | Loose PWM lead | Reseat the signal wire — 3 leads share one pin, find the loose one |
| Blower always full speed | PWM lead on 5V by mistake | Signal must go to D10/D11/D12 only |
| Blower weak | Low duty cycle / low bus voltage | Increase duty; verify 12V at the fan bus |
| Blower vibrates excessively | Mount loose / unbalanced | Tighten mount; check impeller clearance |

---

## 8. Motor issues

| Symptom | Likely cause | Fix |
|---|---|---|
| Motor doesn't run | SSR not switching | Check D5/D7/D9 wiring and the SSR output side (see §5) |
| Motor stalls under load | Insufficient torque | Verify umbrella load (<3 kg·cm); check 12V supply |
| Motor holds when off | That's correct! | SGM-370 worm gear is self-locking by design |

---

## 9. Thermal issues

| Symptom | Likely cause | Fix |
|---|---|---|
| Thermal cutoff triggers immediately | DS18B20 reads >65°C at boot | Move probe away from direct contact with heater; mount in air stream |
| PTC heaters don't get hot | SSR not switching / wrong voltage | Verify 12V at PTC terminals; check SSR wiring (§4); confirm 12V heaters (not 220V) |
| Chamber too hot (>60°C) | Multiple stations active | Ensure staged operation (firmware enforces one at a time); check `activeStation` rotation |
| Burning smell | Wiring too thin / loose | Check wire gauges (10 AWG heater branches, 8 AWG main); tighten all terminals |

---

## 10. Battery issues

| Symptom | Likely cause | Fix |
|---|---|---|
| Battery voltage drops fast | High current draw / old battery | Run staged operation; check for shorts; verify BMS functioning |
| Battery won't charge | Wrong charger | Use 14.6V LiFePO4 charger ONLY |
| BMS disconnects | Over-discharge / over-current | Recharge; check total current draw stays within BMS limits |

---

## 11. Over-current protection (no-fuse design)

There are no fuses in this build — the 200A BMS is the backstop.

| Symptom | Likely cause | Fix |
|---|---|---|
| Station commanded ON but nothing runs | BMS tripped or branch open | Measure 12V at the positive bus bar; if 0V, power-cycle the battery to reset the BMS; check for shorts |
| BMS disconnects under load | Draw exceeds BMS limit | Verify staged operation (one station at a time ≈ 39A); check for shorts |
| Branch dead but bus bar live | Branch wiring open | Trace the 10/18 AWG branch and its SSR output side with a multimeter |
| Burning smell / hot wire | Overload or loose terminal | Stop: flip the 50A rocker OFF; check gauges and tighten terminals |

---

## 12. Debug mode

Add to sketch for verbose Serial output:

```cpp
// Add in loop():
Serial.print("Phase: "); Serial.print(currentPhase);
Serial.print(" | Stn: "); Serial.print(activeStation);
Serial.print(" | H: "); Serial.print(humidity);
Serial.print(" | T: "); Serial.print(temperature);
Serial.print(" | PTC1: "); Serial.print(digitalRead(PIN_SSR_PTC_1));
Serial.print(" | PTC2: "); Serial.print(digitalRead(PIN_SSR_PTC_2));
Serial.print(" | PTC3: "); Serial.print(digitalRead(PIN_SSR_PTC_3));
Serial.print(" | FAN: "); Serial.println(digitalRead(PIN_SSR_FAN_BUS));
Serial.print(" | LID: "); Serial.println(digitalRead(PIN_REED));
```

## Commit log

2026-09-13 Replan to Rev 4: three independent motor stations, verified compatibility, procurement pack
    - 3x SGM worm gear motors (one per umbrella) replace the single-motor
    carousel; per-station 3A fuses give fault isolation
    - SSR + BTS7960 replaced by optocoupler relay modules (on/off control
    only); 25A main fuse sized for 3-motor stall worst case
    - MLX90614 IR sensor removed from the design
    - Add verified Lazada/makerlab.ph sourcing (BOM, PROCUREMENT) and a
    store-grouped SHOPPING_CHECKLIST; corrected totals (~PHP 14.9-15.9k)
    - Untrack local-only references/ folder via .gitignore
    🤖 Generated with Codebuff
2026-09-13 Consolidate docs into docs/BOM.md, add engineering docs, refresh repo metadata
    - Fold the itemized Lazada BOM and the shopping checklist into
    docs/BOM.md as section 14 + Appendix A; remove root BOM.md and
    SHOPPING_CHECKLIST.md so there is a single BOM document
    - Add FLOWCHART, BLOCK-DIAGRAM and SYSTEM-ARCHITECTURE (mermaid),
    plus SETUP, FIRMWARE-GUIDE and TROUBLESHOOTING guides
    - README: drop local-only references/ mention, link the full doc set,
    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
2026-09-13 Add dimensioned 3D model views, rewrite build guide, strip icons from docs
    - model/: representative 3D model in 6 dimensioned PNG views (exploded,
    front, side, top, front-right, front-left) plus a generator script and
    dimension table; chamber sizes are marked adjustable since the paper
    fixes none
    - docs/SETUP.md: rewritten as a strictly ordered student build guide
    (Parts 1-5, numbered steps with pass checks per step)
    - Wiring audit fixes: PTC blower and chamber fan ride the heater branch
    behind the 15 A fuse; rocker switch specified as control-side only;
    10k pull-ups on relay optocoupler inputs documented
    - All emojis/icons removed from README and docs; README gains an
    in-order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
2026-09-13 Rescale 3D model to the decided real chamber box
    Geometry review found the old 1400 mm chamber could not hold three
    canopies (325 mm overflow). Decided layout: umbrellas dry half-open
    (projected 650 mm), three stations in a row at 700 mm pitch inside a
    2200 x 800 x 1300 mm internal chamber. All clearance checks now pass
    (75 mm at walls, 50 mm between canopies); six views regenerated and
    HARDWARE.md layout section updated from "pending" to the decision.
    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
2026-09-13 Accurate v2 model generator: true-scale orthographic views, verified layout
    Replace the approximate renders with an engineering-correct generator:
    front/side/top are true-scale 2D drawings in exact mm with red
    dimension lines; 3D parts rebuilt correctly (cylindrical shafts and
    couplings, 8-rib canopy, heater grille, bladed fan, drain tube and
    tray, sloped floor wedge, door with latch, leveling legs). A layout
    assertion suite now runs before every render and fails on any
    clearance or fit violation - it caught and fixed a heater/fan
    floor-burial error (centers raised to z=220) during this change.
    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
2026-09-13 Remove auto-generated model renders as inaccurate
    Delete the six PNG views and the generator script - the renders were
    not trustworthy as dimensioned references (no visual verification was
    possible for the mesh output). model/README.md now records the binding
    decided dimensions, marks the views as to-be-produced, and recommends
    proper CAD (FreeCAD/Fusion/SolidWorks) or hand drafting instead.
    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
2026-09-13 Add wiring folder with master Mega 2560 connection reference
    Pin-by-pin table (D2-D13, 20/21), 12 V power distribution tree with
    per-branch fuses, component-by-component terminal tables (DHT22,
    DS18B20, LCD I2C, relay boards, motors, heater chain, LEDs/buzzer/
    button), and the safety rules from the wiring audit.
    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
2026-09-13 Rev 5: move heating to 220V AC mains — 2x 1500W PTC heater-fans via 2x Fotek SSR-40DA, 12" Omni exhaust fan
    Battery (12V LiFePO4) now powers motors + control only. Adds mains safety
    layer (RCD, 10A branch fuses, grounded box, kill switches), updates pin map
    (D4/D5 SSR inputs), removes the 30A DC heater relay and 100W PTC from
    procurement, and retitles all docs to Rev 5.
    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
2026-09-13 Fold PROCUREMENT into docs/BOM.md as SOURCING-ANNEX; clean formatting; purge old-revision components
    docs/PROCUREMENT.md renamed to docs/SOURCING-ANNEX.md with cleaned header,
    dead Rev 4 sections removed (1-CH 30A relay, 12V PTC heater, empty heater
    stub), and watch-outs updated. README/BOM cross-references updated. Fixed
    7 formatting defects (double-space headings, list items, empty table cells,
    stray punctuation). Verified: no MLX90614, 100W PTC, 120mm fan, 30A relay,
    carousel, SSR-25DD or BTS7960 remains as an active component anywhere.
    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
2026-09-13 Final doc polish before CAD work: fix SSR boot-bias error (pull-down, not pull-up), purge stale Rev 4 labels, write CAD brief
    Safety-critical fix: SSR-40DA inputs are active-HIGH, so the boot-hold
    resistor is a 10k pull-down (input+ to input-) — the docs previously said
    pull-up, which would energize both heaters at power-on. Relay boards
    (active-LOW) keep their pull-ups. Also: model/README.md is now the working
    brief for the Fusion 360 + Cirkit Designer deliverables; stale Rev 4 labels
    updated in README, FLOWCHART, HARDWARE, STACKS, wiring.
    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
2026-09-13 Remove Rev 4→5 change summary from docs/BOM.md
    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
2026-09-13 Remove changed/unchanged wording from docs/BOM.md headings
    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
2026-09-13 Rev 6: dual-source power — wall outlet OR 3000W pure sine inverter via changeover switch
    Battery bank upgraded to 2x 200Ah LiFePO4 (parallel, BMS 200A each) with a
    14.6V 20A charger. A 2P 63A changeover feeds the RCD from either the wall
    outlet or the inverter — never both — and grounds the inverter remote pin
    in wall mode (zero idle draw). Mega D14 senses the mode; firmware caps
    battery mode at stage 1 (heater 1 + fan ~2.05kW = 68% of inverter, 221A DC
    peak vs 400A BMS aggregate). Updated BOM, wiring, block diagram,
    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
2026-09-15 Anonymize docs; swap SSR-40DA to dedicated Makerlab listing (₱160 ea)
    - Remove student names, school, and campus from README, SOURCING-ANNEX, references title page
    - SSR-40DA: old multi-variant listing (₱850 ea) → dedicated DA listing (₱160 ea, SKU MLE00140)
    - Update cart totals: electronics ₱3,952→₱2,572, total ₱45,000–49,500→₱43,600–48,100
2026-09-15 Rev 7: Complete 12V DC redesign — all docs rewritten
    Major architecture change from 220V mains + inverter to pure 12V DC:
    - 9× PTC ceramic heaters (12V 100W, CHLOCH BAG assemblies)
    - 9× BLDC ducted fans (50mm, 12V, ESC-controlled via PWM)
    - 3× SGM-370 worm gear motors (14 kg·cm, 6 RPM)
    - 2× LiFePO4 200Ah batteries in parallel
    - Relay switching for heaters + motors, ESC PWM for fans
    - No mains, no inverter, no RCD, no changeover switch
    All 13 docs rewritten: BOM, HARDWARE, BLOCK-DIAGRAM,
    SYSTEM-ARCHITECTURE, FIRMWARE-GUIDE, FLOWCHART, STACKS,
    SETUP, TESTING, TROUBLESHOOTING, SOURCING-ANNEX, README,
    model/README.
    KP06→KP08 pillow blocks (6mm bore insert) verified.
    SOURCING-ANNEX now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
2026-09-15 Clean up all Rev references across docs, rewrite wiring/README
    - Remove all Rev 7/6/5/4/3/2/1 version labels from headers and text
    - Remove Rev from Arduino serial print and LCD display strings
    - Rewrite root README.md for current 12V DC architecture
    - Rewrite wiring/README.md — pure 12V DC, no mains/inverter/SSR
    - KP06→KP08 pillow blocks verified across all docs
    - Keep revision history table in HARDWARE.md for traceability
    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
2026-09-15 Fix PTC heater link: CHLOCH BAG (dead) → MXKJING T30 (LazMall)
    - MXKJING T30: ₱484/ea (was ₱555 CHLOCH BAG) — save ₱639 total
    - LazMall seller, 95% rating, 30-day return
    - URL: https://www.lazada.com.ph/products/pdp-i15593670246.html
    - Updated BOM, SOURCING-ANNEX, cost summaries
2026-09-15 Source all electronics from Makerlab PH (Lazada)
    - Arduino Mega 2560: ₱430 clone → ₱1,165 Makerlab PH
    - DHT22 module: ₱69 generic → ₱210 Makerlab PH
    - Relays: 3× 2-CH ₱309 → 6× 1CH ₱294 Makerlab PH
    - LM2596S: ₱155 generic → ₱49 Makerlab PH
    - All links verified: Makerlab PH store (98%, 10-yr, Bulacan)
    - Grand total updated: ~₱34,900–35,600
2026-09-15 BOM: remove duplicate §6 Sensors & §7 UI tables, fix 8 dead URLs, align PTC to MXKJING T30
    - Deleted §6 (Sensors) and §7 (UI) — exact duplicates of items already in §1 and §4
    - Renumbered sections 1–12 sequentially
    - Replaced 7 dead Lazada product URLs with stable catalog/search pages
    - Aligned Appendix A Cart B PTC heater from CHLOCH BAG (₱4,995, 404) to MXKJING T30 (₱4,356, live)
    - Updated §13 cross-references in shopping checklists
2026-09-16 Rev 8: site-wide wiring fix — fuses, relays, pin map, staged operation
    Major engineering fixes across all 15 docs:
    - Main fuse: 25A blade → 50A ANL (one station draws ~36A, 25A blew)
    - PTC relays: 6× 10A PCB modules → 4× 40A automotive (NPN-driven)
    PTC draw = 25A per station, far over 10A PCB relay rating
    - Thermal fuse: 80°C (too close to operating temp) → 130°C per heater (9×)
    Rated 10A each, mounted in individual heater + leads
    - Fan bus fuse: 15A → 30A (9 fans × 3.2A = 28.8A at full speed)
    - Station PTC fuses: 10A → 30A (3× PTC = 25A, 10A fuse would blow)
    - Kill switch: 10A DC rocker → 50A disconnect (can't handle 36A)
    - Pin map reconciled: D4/D6/D8=PTC, D5/D7/D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
2026-09-16 Battery capacity recomputation: LiFePO4 usable capacity, per-cycle energy
    - Usable = 400Ah x 0.80 DoD x 0.90 EoL = 288 Ah (was using 100% nameplate)
    - Load profile: staged active 35.5A, COOL 10.3A, standby 0.5A
    - Energy per cycle: quick (27 min) 15 Ah; standard (57 min) 33 Ah
    - Runtime: 19 quick / 8.8 standard cycles per charge; 8.1 h continuous
    - Capacity requirement table: demo 126Ah, typical 210-365Ah, heavy 548Ah
    - Verdict: 2x 200Ah adequate for capstone + typical use; heavy day needs
    overnight recharge (~14h at 14.6V/20A)
    - C-rate check: 0.09C bank / 0.18C per pack, far under 200A BMS
    - Fixed stale runtime claims in BOM, HARDWARE, SYSTEM-ARCHITECTURE, README
2026-09-16 Switch from 2× to 1× LiFePO4 200Ah battery
    - 1 battery (144 Ah usable @ 80% DoD × 90% EoL)
    - 9.6 quick cycles (~29 umbrellas) per charge
    - 4.4 standard cycles (~13 umbrellas) per charge
    - 4.1 h continuous staged runtime
    - Capstone demo (18 umbrellas) fits with ~40% margin
    - Cost drops ₱36k→₱27k (₱8,900 battery savings)
    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
2026-09-16 Fix all remaining 2-battery stale references across 10 files
    - HARDWARE.md: mermaid diagram 2×→1×, runtime table 288→144 Ah, 19→9.6 cycles, 8.8→4.4 cycles, 8.1→4.1h
    - SYSTEM-ARCHITECTURE.md: both mermaid diagrams 2×→1×
    - STACKS.md: battery count 2×→1×
    - SOURCING-ANNEX.md: battery qty 2→1, grand total ₱36k→₱27k, restored rev history (₱40.8k)
    - README.md: core components table 2×→1×
    - wiring/README.md: domain table 2×→1×
    - docs/README.md: power line 2×→1×, cost ₱36k→₱27k
    - SETUP.md: unbox checklist 2×→1×
    - model/README.md: battery compartment 2×→1×
    - BLOCK-DIAGRAM.md: mermaid battery node 2×→1×
2026-09-16 Final cleanup: strip AI-ish prose, remove duplication, tighten docs
    Prose:
    - Removed 'canonical' overuse across 5 files (wiring, BOM, FLOWCHART, model, README)
    - 'Eliminated entirely' → 'No mains voltage in the system'
    - 'The design intent' → 'Firmware enforces this limit'
    - 'eliminates mains wiring' → 'no mains wiring, no RCD, no changeover'
    - 'sampling step' → 'loop interval'
    - 'Relay architecture (why)' → 'Relay architecture'
    - Removed 'Rev 8, canonical' from file headers (BOM, wiring)
    - Removed 'Rev 8 changes' changelog blocks (BOM, HARDWARE, BLOCK-DIAGRAM)
    Structure:
    - Root README: removed duplicate Documentation table (kept Where to start)
    - docs/README.md: rewritten — sho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
2026-09-17 Update 12V power distribution bus bars
2026-09-17 Swap in taxnele SSRs, SSR heatsink, LM2596S with display
2026-09-17 Switch to AVC 12V 4.5A blowers (no ESCs), update BOM with new Lazada links/prices
    - Replace 9× BLDC ducted fans + ESCs with 9× AVC Super High Speed Blower DC 12V 4.5A (pdp-i2328323489, ₱330 ea)
    - Fans controlled via direct PWM from Mega D10/D11/D12 (analogWrite) — no ESC, no Servo library
    - Update DS18B20 to LEOOYI module w/ terminal adapter + 3pin cable (pdp-i4398946755, ₱141)
    - Update Mega to terminal board version (i123143829, ₱413)
    - Update DHT22 to module variant (pdp-i132179919, ₱220)
    - Update LM2596S to w/display variant (pdp-i127879071, ₱155)
    - Add full Lazada URLs for all BOM line items
    - Update SSR heatsink to BLACK 10A-40A (i3585835660, ₱110 ea)
    - Bus bar price cor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
2026-09-17 Clean up residual ESC/opto references in HARDWARE.md and wiring/README.md
    - Remove all ESC→BLDC references from block diagrams (replaced with PWM→AVC blower)
    - Update motor SSR references: opto module (active-LOW) → SSR-10DD (active-HIGH)
    - Remove 4-CH optocoupler module mentions from wiring docs
    - Update pin maps: D5/D7/D9 now SSR-10DD direct drive (HIGH=ON)
    - Update D10/D11/D12 descriptions from ESC PWM to Blower PWM
    - Clean up all remaining BLDC fan references
2026-09-18 Add 50A DC rocker switch for main power disconnect + update LCD link
    - Add 50A 12V DC heavy duty toggle switch (~₱190) as main power disconnect
    - Installed between battery + and positive bus bar (8 AWG)
    - Emergency kill = flip rocker OFF + unplug battery cable
    - Update LCD link to Makerlab 1602 16x2 I2C (i104139284-s1630402476)
    - Update BOM, SOURCING-ANNEX, HARDWARE, wiring docs
    - Total: ≈ ₱27,800–28,000 (was ≈ ₱27,600–27,800)
2026-09-18 Update LED and active buzzer links to Makerlab PH listings
    - LED 5mm assorted colors: i144137387 (₱109, Makerlab)
    - Active alarm buzzer driver module: i3474748260 (₱35, Makerlab)
    - Updated BOM.md and SOURCING-ANNEX.md
2026-09-18 Replace Dupont jumper kit with Model 1007 tinned copper wire kit (2 variants)
    - Swap Dupont jumper 40-pin (₱45) → 2× Model 1007 tinned copper wire kit (COLOR 01 + 02)
    - 18/20/22/24 AWG, 5-color spool each (i3154761672, ₱385 ea = ₱770)
    - Covers logic + signal wiring (Mega → SSR, sensors, buttons, LED)
    - Updated BOM.md, SOURCING-ANNEX.md, TROUBLESHOOTING.md
    - Total: ≈ ₱28,500–28,700 (was ≈ ₱27,800–28,000)
2026-09-18 Update terminal block (6-pole), resistor kit, standoff specs, and LiFePO4 charger
    - Terminal block: specify 6-pole for 5V rail distribution (buck → Mega/DHT22/DS18B20/LCD/button), ₱132
    - Resistor kit: upgrade to 1% Metal Film 600pcs (47Ω/220Ω/1K/10K/47K/68K/100K/220K/1M, Makerlab PH, ₱220)
    - Nylon standoffs: specify M3/M2.5 combo — M3x6+6mm×30, M3x10+6mm×20, M2.5x6+6mm×20 (covers Mega, LCD, SSR mounts)
    - LiFePO4 charger: specify VariCore 14.6V 20A alligator clip variant (₱2,809)
    - Battery + charger subtotal updated to ≈ ₱11,700–12,200
    - New total: ≈ ₱29,300–29,500
2026-09-18 Add links and specs for zip ties, screws, sealant, and grommets
    BOM.md:
    - Zip ties 100pcs nylon UV-resistant, heavy duty (i4164586303, ~₱84)
    - Screws M3/M4/M5 stainless 320pcs kit (i15532367775, ~₱298) - M3 for Mega mount
    - PROSEAL silicone sealant clear, 100% RTV waterproof (i4013402307, ~₱199)
    - Rubber grommets 180pcs 8 sizes (i3692147637, ~₱249)
    - Wiring/consumables subtotal ≈ ₱2,500-2,900; new total ≈ ₱29,600-29,900
    SOURCING-ANNEX.md:
    - Replace generic hardware-store table with verified online links + specs
    - Add note: online ~₱830 vs bulk hardware ~₱490 (pick cheaper after shipping)
2026-09-18 Remove shaft/pillow blocks: SGM-370 drives umbrella hub directly via PETIYOUZA 6mm flange coupling
    - Remove 3× SS shafts, 6× KP08 pillow blocks, 2× rigid 6×8 couplings (₱1,228 saved)
    - Add 3× PETIYOUZA rigid flange coupling 6mm (i4018785636, ~₱107 ea = ~₱321)
    - Driver: SGM-370 output shaft couples directly to umbrella hub; no intermediate shaft
    - Update BOM (motors+couplings ≈ ₱1,821), SETUP, HARDWARE, SOURCING-ANNEX, model/README, TROUBLESHOOTING
    - Commit wiring circuit files (UmbrellaDryerV2.ckt, circuit_image.png) from CirKit Designer
    - New total: ≈ ₱28,700–29,000
2026-09-18 Restore drivetrain (rigid coupling, shaft, UCP06 pillow block) across all docs
    Bring back the full mechanical chain per station: SGM-370 motor → rigid
    coupling 6×8mm → 6mm×300mm SS shaft → UCP06 pillow block (shaft mid-span)
    → PETIYOUZA 6mm flange coupling → umbrella hub, mounted on aluminum plate.
    Adds BOM rows (~₱1,228), one-page printable shopping checklist, and removes
    stale relay/ESC/fuse references left over from the SSR conversion.
    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
2026-09-18 Audit fixes: humidity auto-stop firmware, unified totals, table repairs
    Critical: add humidity-based early stop to the DRY phase (≤60% RH after
    ≥3 min — the study's energy-efficient control, previously timer-only);
    fix SOURCING-ANNEX stale totals; rebuild broken BOM §3a/§4 tables; fix
    dead RELAY_M nodes in HARDWARE block diagram.
    Consistency: unify per-station draw at 39.3A across all docs; correct
    rigid-coupling price (pack of 3 = ₱249); replace XT60 with screw
    terminals per BOM; fix "Blowes" typos; SSRs energize (not "click");
    repair broken `||` table rows in 6 files. Totals now ≈₱29,000 everywhere.
    🤖 Generated with Codebuff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
2026-09-20 Replace PTC heater link in BOM: MXKJING T30 (out of stock) -> diymore 12V 100W
    Original Lazada listing i15593670246 no longer available. Replaced with
    diymore DC 12V 100W PTC ceramic heater (select 12V100W variant).
    Price :484 -> :1,162 ea (9x = :10,460). Updated section 4, section 9
    line item, cost summary, and total (:29k -> :35.1k).
2026-09-25 Rev 10: Add lid safety interlock (reed switch D22 + solenoid lock D23)
    - Source: Makerlab PH on Lazada (reed switch ₱165, solenoid lock ₱310)
    - Add 4th SSR-10A (D23) for solenoid lock control
    - Firmware: gate start on lid-closed reed (D22 LOW), fail-secure lock during cycle, pulse unlock at COMPLETE
    - Update all guides: wiring, hardware, BOM, sourcing, setup, testing, troubleshooting
    - Total cost: ≈ ₱35,800 (was ₱29,000; PTC now ₱1,162 ea + new interlock parts)
2026-09-30 Included 3d model files
    [DCWormGearMotor.f3z, SSRHeatsink.f3z, UMBRELLADRYERV2.f3z]
2026-10-01 Add CirKit Designer schematic link to wiring README
